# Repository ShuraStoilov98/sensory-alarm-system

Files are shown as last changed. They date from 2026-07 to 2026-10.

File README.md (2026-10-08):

# Sensory Alarm System

An ESP32 alarm that opens bedroom curtains with a stepper motor and a printed mechanism. A physical direction switch and hold-to-run button provide manual control; end stops and a five-second timeout bound each movement.

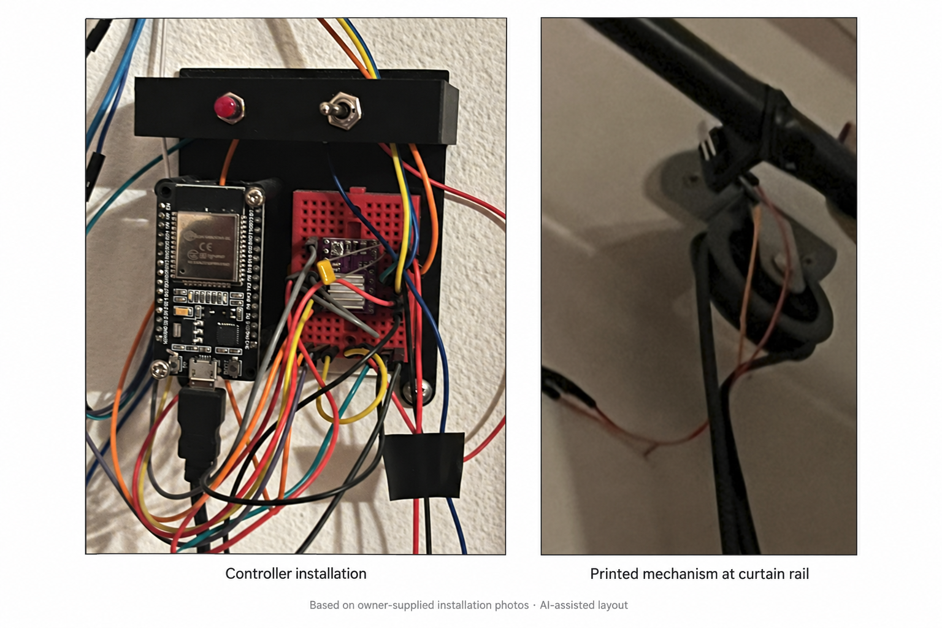
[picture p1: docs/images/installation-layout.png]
Photo-based layout of the original controller installation and printed curtain mechanism


*Based on the owner's installation screenshots; [AI-assisted layout](docs/images/installation-layout.txt). The controller close-up leads, with the curtain mechanism alongside it.*

[Wiring](docs/Electrical.md) · [Printable parts](docs/Mechanical.md) · [Hardware checks](docs/Validation.md) · [Public readiness](docs/public_readiness_report.md)

## The build

Simona Todorova and Alexander Stoilov built the original version over Christmas weekend in December 2024, using an Arduino Mega2560 for motor control, an ESP32 for WiFi/time, SolidWorks CAD, and a physical curtain installation.

Alexander's subsequent work migrated the firmware to PlatformIO and simplified the electronics to a single ESP32. The October 2026 public-readiness pass added hold-to-run control, cooperative motor stepping, latched faults, reliable offline manual control, daylight-saving rules, and date-based alarm tracking. Contributor names and original commit dates remain; personal email and CAD source-path metadata have been removed from the published historical revisions.

**Status:** personal hardware prototype. The earlier build was reported working; the revised firmware has automated behavior checks and a compile check, but still needs validation on the assembled hardware. The supplied installation photographs document the earlier assembly. An operating video is outside this release scope; the CAD animation below illustrates the original printable designs.

## Wiring

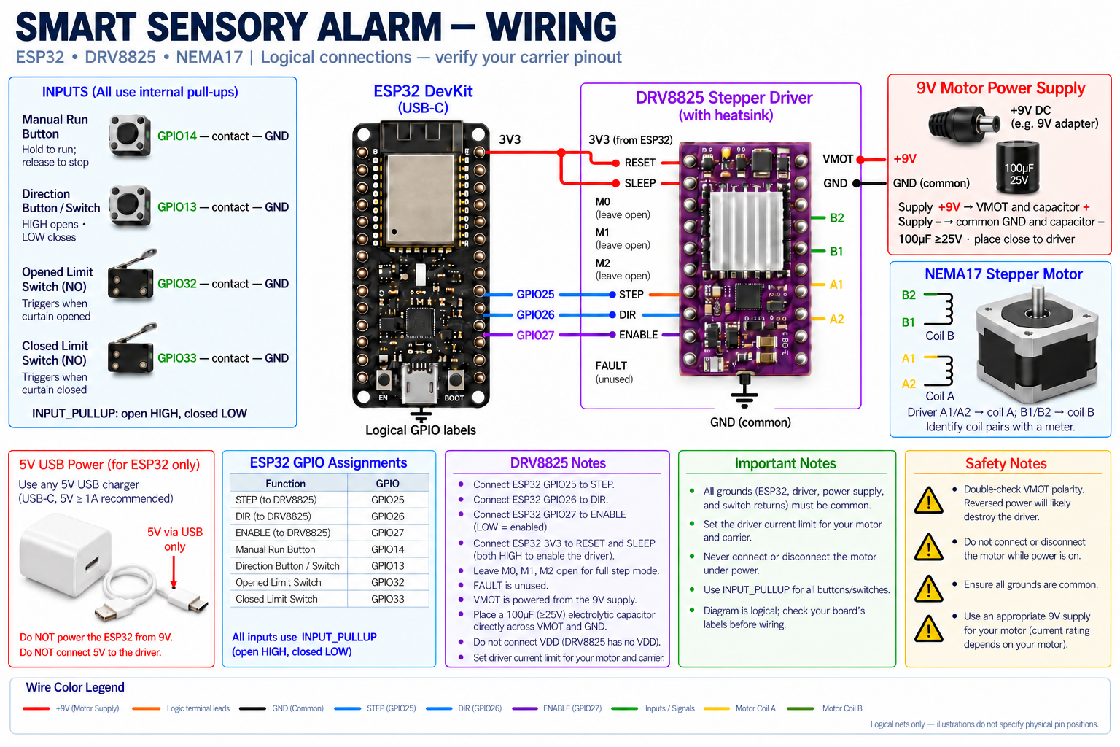
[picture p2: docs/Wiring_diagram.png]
ESP32 curtain alarm wiring: switches, DRV8825, motor and separate power supplies


*Regenerated logical wiring illustration. Follow the [connection tables](docs/Electrical.md) and check your actual board labels before assembly.*

## Printed mechanism

These are previews embedded in the original CAD exports, rather than photographs of the installed build. Download the models and read the [printing and assembly notes](docs/Mechanical.md).

| Curtain puller | Controller and driver holder | Button holder |
| --- | --- | --- |
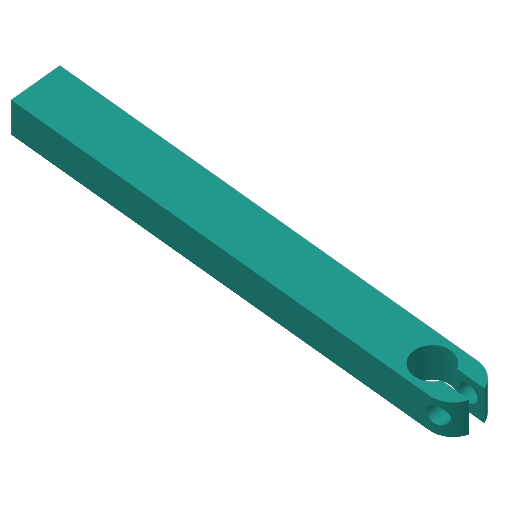
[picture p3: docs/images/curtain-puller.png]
Curtain puller CAD preview
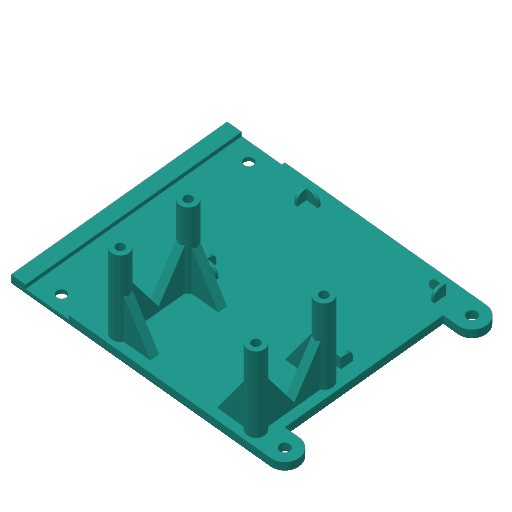
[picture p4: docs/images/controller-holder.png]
ESP32 and driver holder CAD preview
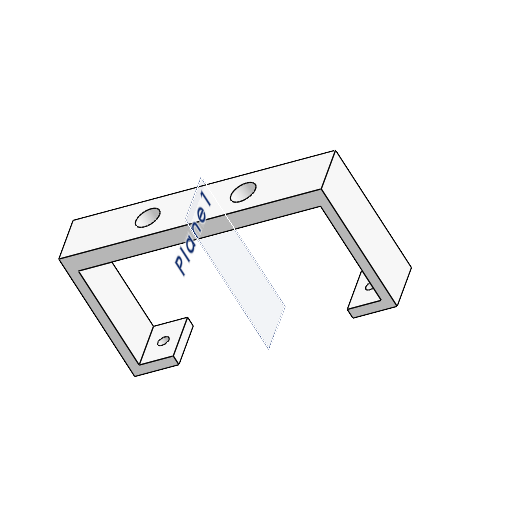
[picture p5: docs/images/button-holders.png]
Button holder CAD preview
|  |  |  |
| [CurtainPuller_v2.3mf](mechanical%20parts/CurtainPuller_v2.3mf) | [ESP32-DRV-BTNs_Holder.3mf](mechanical%20parts/ESP32-DRV-BTNs_Holder.3mf) | [Button_holders.3MF](mechanical%20parts/Button_holders.3MF) |

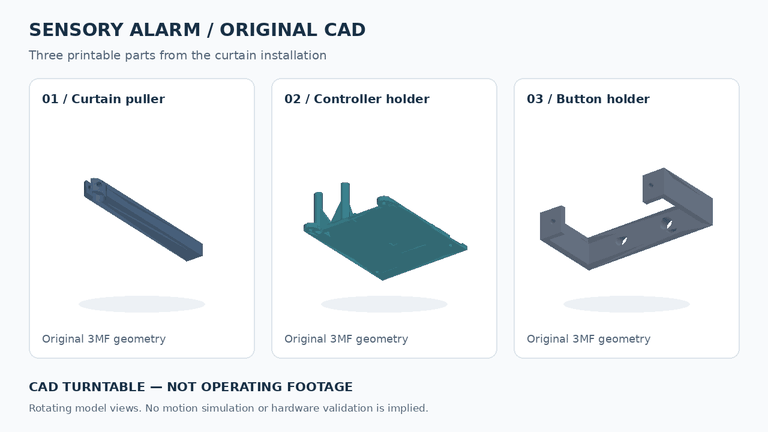
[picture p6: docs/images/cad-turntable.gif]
Rotating views of the three original CAD models, explicitly labeled as a CAD render


[Download the six-second CAD video](docs/images/cad-turntable.mp4). These are rotating views of the actual 3MF geometry, not footage of curtain operation. [Regenerate the render](tools/render_cad.py).

## How it works

```mermaid
flowchart LR
    TIME["WiFi and NTP"] --> ESP["ESP32"]
    BUTTON["Hold-to-run button and direction switch"] --> ESP
    LIMITS["Open and closed end stops"] --> ESP
    ESP -->|STEP DIR ENABLE| DRIVER["DRV8825"]
    DRIVER --> MOTOR["NEMA17"]
    MOTOR --> CURTAIN["Printed curtain mechanism"]
```

- **Manual:** select direction, then hold the run button. Release stops immediately on the next loop. Changing direction stops the current run; release and press again to move in the new direction. Manual control works without WiFi or valid time.
- **Automatic:** open at **06:30 Bulgarian local time**, with winter/summer timezone rules. The alarm can be evaluated throughout that minute; there is no late catch-up. A button press interrupts automatic movement, and manual activity during the scheduled minute suppresses that day's automatic run.
- **Daily tracking:** the automatic attempt date is saved in ESP32 NVS before movement, preventing a repeat after restart. An already-open curtain or manual/fault override consumes the day too; skipped dates encountered during travel are saved after movement stops. A power loss before that deferred save can lose the skipped-date record.
- **Motor:** STEP pulses are generated cooperatively, with 500µs minimum high/low intervals. No catch-up pulse bursts are emitted. WiFi reconnect requests and flash writes are deferred during travel.
- **Faults:** a five-second timeout or both limit switches active disables the driver and latches a fault until restart. Inspect the wiring and mechanism before restarting. A button held during boot must first be released.

The alarm time, GPIO assignments, timezone rules, and motor settings live in [config.h](src/esp32/config.h). Persisted attempt dates are independent of the compiled alarm setting; reflashing or rebooting is not a routine way to re-run today's alarm.

## Firmware structure

| File | Responsibility |
| --- | --- |
| [main.cpp](src/esp32/main.cpp) | Startup and cooperative loop |
| [config.h](src/esp32/config.h) | Pins, schedule, timezone and timing |
| [curtain_controller.cpp](src/esp32/curtain_controller.cpp) | State-aware command guards, limit checks, faults and step edges |
| [manual_input.cpp](src/esp32/manual_input.cpp) | Debounced hold-to-run input and physical override |
| [alarm_scheduler.cpp](src/esp32/alarm_scheduler.cpp) | Daily schedule and persistent attempt tracking |
| [network_clock.cpp](src/esp32/network_clock.cpp) | Idle WiFi recovery and SNTP startup |

The controller reports motion, limit-derived position, command source and fault cause separately. With neither end stop active, position is **unknown**. Busy requests cannot reverse an active movement; stop preserves latched faults. Manual input and the alarm share the same guarded command API. See the [state transitions](docs/improvements_brief.md#controller-state).

## Build and flash

Requires an ESP32 DevKit compatible with PlatformIO's `esp32dev` definition, a data-capable USB cable, and [PlatformIO Core or its VS Code extension](https://docs.platformio.org/en/latest/core/installation/index.html). The platform and Arduino framework revision are pinned in [platformio.ini](platformio.ini).

Copy the credential template, then edit only the local copy:

```bash
cp include/secrets.example.h include/secrets.h
```

`include/secrets.h` is ignored by Git. Keep personal credentials out of commits, screenshots, and downloadable firmware; compiled firmware contains the supplied credentials.

Compile, identify the serial port, then flash and monitor:

```bash
pio run --environment esp32
pio device list
pio run --environment esp32 --target upload
pio device monitor
```

The serial monitor uses **115200 baud**. If upload cannot connect, hold the board's BOOT button while connecting. Initially disconnect the motor PSU and verify logic before introducing motor movement. Follow the [wiring reference](docs/Electrical.md) and [commissioning checklist](docs/Validation.md) before running the assembled mechanism.

## Verification

Run the firmware behavior tests with Python 3 and a C++17 compiler on Linux, macOS or WSL:

```bash
python3 test/run_host_tests.py
```

The tests execute the actual firmware with fake GPIO, WiFi, flash storage, and clocks. They cover offline control, release-to-stop, debounce, alarm/manual interaction, timeout faults, end stops, persistent dates, timer rollover, and seasonal timezone behavior. They do not establish motor timing or electrical safety on the real board. [GitHub Actions](.github/workflows/checks.yml) runs the behavior tests and compiles with placeholder credentials; no firmware artifacts are uploaded.

Record physical results in [Validation.md](docs/Validation.md), including the actual carrier/motor model, current limit, curtain travel time, and end-stop behavior.

## Limitations and future work

End stops are polled by firmware and are not an independent hardware emergency stop. An unplugged switch reads inactive with the current pull-up wiring; there is no obstruction sensing. Driver disable at boot depends on software until the ESP32 configures the GPIO. Mechanical loads and restart behavior need physical validation.

Software-generated step timing can vary with ESP32 background work. Acceleration, editable/persistent alarm settings, a web interface, and OTA updates are not implemented. The [improvements brief](docs/improvements_brief.md) describes future extensions. The firmware is split into focused modules, with [main.cpp](src/esp32/main.cpp) coordinating input, movement, network recovery and scheduling.

The compile-tested PlatformIO baseline uses Arduino 2.0.17 / ESP-IDF 4.4.7. ESP-IDF 4.4 is [past vendor support](https://github.com/espressif/esp-idf/releases/tag/v4.4.8); a supported SDK migration remains necessary before treating this legacy prototype as maintained network-connected firmware.

## License

[MIT](LICENSE). See the build background above for original contributor credit.

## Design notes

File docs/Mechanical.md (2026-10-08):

# Printed parts and assembly

The repository contains three original 3MF exports from the curtain build. The previews below were extracted from those files; they show the designs rather than an installed or tested assembly.

| Part | Preview | Download |
| --- | --- | --- |
| Curtain puller | Curtain puller model | [CurtainPuller_v2.3mf](../mechanical%20parts/CurtainPuller_v2.3mf) |
| ESP32, driver and button holder | Controller holder model | [ESP32-DRV-BTNs_Holder.3mf](../mechanical%20parts/ESP32-DRV-BTNs_Holder.3mf) |
| Button holder | Button holder model | [Button_holders.3MF](../mechanical%20parts/Button_holders.3MF) |

## Installation and render

The [installation layout](images/installation-layout.png) uses the owner's controller close-up and curtain-mechanism screenshot as references, with AI-assisted formatting disclosed. It documents the earlier build's appearance rather than the revised firmware's operation.

Rotating original CAD models

[Download the CAD turntable video](images/cad-turntable.mp4). This six-second render uses the repository's three original 3MF meshes and assembly transforms. It shows rotating model views rather than a working mechanism or a motion simulation. An operating video is outside the current portfolio scope.

To regenerate the animation, install `numpy==2.3.3`, `Pillow==11.3.0` and `imageio-ffmpeg==0.6.0` in an optional tooling environment, then run `python3 tools/render_cad.py`. These packages are not firmware dependencies.

## Preparing a print

Open a 3MF in your slicer and inspect dimensions, orientation, supports and mounting holes. Two files contain a Bambu Studio export with a Flashforge Adventurer 5M 0.4mm-nozzle profile; choose settings for your own printer instead of treating those saved settings as validated print instructions. The exports contain model geometry and settings, not a prescribed ready-to-run print job.

The public-readiness pass removed Windows source-file paths from the two slicer archives. Their geometry and all other archive entries were preserved. The same metadata removal was applied to local historical copies; geometry and contributor attribution remain.

## Assembly details to record

The original installation was fitted to bedroom curtains. Reproducing that installation requires these physical details, which have not yet been recorded:

- Curtain/rail type, travel distance and load.
- Shaft coupling, fasteners, mounting dimensions and attachment method.
- Filament, orientation, layer height, walls/infill and required supports.
- Placement and actuation of both limit switches.
- Driver ventilation, cable strain relief and access to disconnect motor power.

Verify fit and mechanical clearance before powering the motor. Begin unloaded, check direction, and position both end stops before attaching the curtain load. Complete the [hardware checks](Validation.md) before describing the revised firmware as hardware-validated. Do not infer load-bearing strength from a CAD preview alone.

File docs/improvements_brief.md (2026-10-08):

# Improvements brief

Updated 8 October 2026. This brief distinguishes implemented behavior from proposed extensions. See the [entry point](../src/esp32/main.cpp) and [configuration](../src/esp32/config.h), the [wiring reference](Electrical.md), [printable parts](Mechanical.md), and [hardware validation](Validation.md).

## Implemented

The project migrated from Arduino IDE/local folders to PlatformIO and from an Arduino Mega plus ESP32 to an ESP32 alone.

The public-readiness pass adds:

- Focused modules for control, physical input, alarm persistence and network/time recovery.
- Cooperative `micros()`-based stepping with IDLE, OPENING, CLOSING and FAULT states.
- A shared guarded command API and separate motion, limit-derived position, control-source and fault status.
- Hold-to-run manual input with debounced starts and release-to-stop.
- Manual interruption of automatic movement and direction-change stop behavior.
- Latched timeout and contradictory-limit faults.
- Manual operation without WiFi/time, with reconnect requests deferred during travel.
- Bulgarian daylight-saving rules and an alarm evaluated throughout its scheduled minute.
- A persistent daily automatic-attempt date, saved before automatic movement.
- Host regression tests and a CI compile check using placeholder credentials.

Physical acceptance of the revised firmware remains pending. The limit-switch reliability issue mentioned in the earlier roadmap needs confirmation on the real mechanism; source changes and compile checks cannot establish closure.

## Current runtime

```mermaid
flowchart TD
    LOOP["loop()"] --> BUTTON["Debounce start / detect manual override"]
    BUTTON --> MOTOR["Check limits, release, direction and timeout; emit step edge if due"]
    MOTOR --> NETWORK["Request WiFi recovery / start SNTP when idle"]
    NETWORK --> ALARM["Check local date and schedule; persist attempt before auto start"]
    ALARM --> YIELD["Yield when idle"]
    YIELD --> LOOP
```

No WiFi connection wait or whole-travel motor loop blocks the application. Background SDK work and short flash operations still take time. Network reconfiguration and flash writes are deferred during movement; software pulse timing remains subject to hardware validation.

## Controller state

[Controller API](../src/esp32/curtain_controller.h) exposes `request(direction, source)`, `stop(reason)` and a read-only `status()` snapshot. Internal state and pulse timers are private. Requests return a result: started, busy, fault latched, already at target, manual override, or invalid source. Rejected requests preserve the current movement; contradictory limits latch a fault immediately.

```mermaid
stateDiagram-v2
    [*] --> IDLE
    IDLE --> OPENING: accepted open request
    IDLE --> CLOSING: accepted close request
    OPENING --> IDLE: open limit / stop / manual release or direction change
    CLOSING --> IDLE: closed limit / stop / manual release or direction change
    OPENING --> FAULT: timeout / contradictory limits
    CLOSING --> FAULT: timeout / contradictory limits
    IDLE --> FAULT: contradictory limits
    FAULT --> FAULT: all commands blocked; stop preserves fault
```

Fault recovery requires inspection and device restart; there is no software fault-clear command. A raw button press stops alarm-driven travel. A released button and new debounced press are required to start manual travel after that interruption.

Position is `OPEN` or `CLOSED` only while the corresponding end stop is active, `UNKNOWN` when neither is active, and `CONFLICT` when both are active. There is no encoder, homing sequence or remembered position estimate. Source is `MANUAL` or `ALARM` during travel and `NONE` after stopping. A consumed alarm date records an attempt, never a confirmed position.

All firmware modules remain under `src/esp32/`, covered by the existing PlatformIO source filter. Host tests compile those translation units separately and exercise the actual command API.

## Proposed extensions

| Extension | Status and prerequisite |
| --- | --- |
| Acceleration and hardware-timed stepping | Not implemented. Measure travel and step timing before changing the drive profile. |
| Supported SDK migration | Not implemented. The compile-tested PlatformIO Arduino 2.x environment uses an end-of-life ESP-IDF 4.4.7 baseline; validate a supported stack before maintained network deployment. |
| Editable alarm settings in NVS | Not implemented. Only the last handled alarm date is persisted; the hour/minute remain compiled settings. |
| Local web interface | Not implemented. Route authenticated open/close/stop commands through the same motor/fault logic. |
| OTA firmware updates | Not implemented. Require authenticated updates and a tested recovery strategy. |
| Light sensor, speaker, multiple curtains or voice integration | Ideas only; each needs its own hardware and behavior validation. |

## Web control design boundary

A possible future interface would offer status and authenticated commands on the local network, with a small device-served page. There is no current HTTP server or OTA endpoint.

Authentication and request validation must be part of the first implementation of actuator/configuration writes, rather than a later hardening phase. A local network alone does not establish caller identity. Define how browser requests are protected against unwanted cross-origin commands, how credentials are provisioned, and how a physical override takes priority. Do not expose the device through port forwarding as a shortcut.

Only persist settings when they change. Keep alarm-attempt tracking independent from editable configuration and avoid flash writes in the movement path.

## Next useful evidence

The supplied controller and mechanism screenshots are now surfaced in the README, with AI-assisted formatting disclosed. A CAD turntable video/GIF uses the original 3MF geometry. Filming an operating demo is outside this release scope.

Complete the [commissioning checks](Validation.md) and record the carrier and motor specifications before claiming the revised firmware is hardware-validated. Those checks can remain pending for a clearly documented prototype source release. See the [publication status and remaining checks](Publication.md).

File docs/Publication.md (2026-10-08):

# Publication decisions and remaining actions

The intended release is a documented personal hardware prototype. Filming a working demo is outside scope. The revised firmware has 22 passing behavior scenarios and an ESP32 compile check; physical acceptance is still pending and is disclosed in the README.

## Decisions made

| Item | Decision |
| --- | --- |
| Historical privacy | Remove personal author/committer emails and historical CAD source-file paths. Preserve contributor names, original dates, commit messages, source files and geometry. |
| Lead installation image | Use the bright controller close-up, screenshot 1. It clearly shows the ESP32, driver, controls and printed mounting. |
| Supporting image | Use screenshot 2 for the curtain mechanism. Its low-light appearance is retained; it provides installation context rather than fine mechanical detail. |
| Alternate images | Omit screenshots 3 and 4; they repeat the controller view with poorer exposure. |
| Image processing | The chat screenshots were not available as local files. The stored contact sheet is generated from those references and labeled as an AI-assisted layout. It is not an untouched screenshot export. |
| Video | Provide a six-second [CAD turntable](images/cad-turntable.mp4), with an [inline GIF](images/cad-turntable.gif). It renders the original 3MF geometry and is explicitly labeled as CAD, not operating footage. |
| Release scope | Publish the current stack as a documented legacy prototype. A supported SDK migration and bench acceptance are future maintenance work, not prerequisites for sharing prototype source honestly. |

## Published repository and future pushes

The cleaned history was published on 8 October 2026 to the independent [sensory-alarm-system repository](https://github.com/ShuraStoilov98/sensory-alarm-system). The initial upload contains 20 commits through `844dc80`, including the final presentation assets. The owner created this destination as public. The original repository's `main` was also updated successfully with an explicit force-with-lease.

The cleanup covered the preceding 19 commits: 30 personal author/committer email fields and two historical CAD path entries were removed. All other CAD archive entries remain byte-identical. Contributor names, dates and messages are preserved; rewritten commit IDs change and existing commit signatures cannot be retained as valid signatures. A follow-up check of all 20 commits on the published branch found no personal email fields or private Windows paths in CAD archives; the checkout secret scan found no credential candidates.

The local `public` remote points to `https://github.com/ShuraStoilov98/sensory-alarm-system.git`, and `main` tracks `public/main`. Future normal updates use:

```bash
git push
```

Push only reviewed branches. Do not publish the entire local ref namespace with `--mirror`, which could include tool-owned checkpoints or old history. The `.git/privacy-cleanup-lease` file records the completed original-repository update; it is local bookkeeping and is no longer the publication procedure.

Keep the original repository private. Re-clone other local copies from the new repository rather than merging previous history into the cleaned branch. An earlier pull fetched the old history locally but stopped before merging; the published `main` remains clean. A new repository isolates this release from the original repository's PR references and cached views, but does not erase old clones, forks or previously exposed copies. See [GitHub's history-cleanup guidance](https://docs.github.com/en/authentication/keeping-your-account-and-data-secure/removing-sensitive-data-from-a-repository).

Confirm [GitHub Actions](https://github.com/ShuraStoilov98/sensory-alarm-system/actions) passes on the published branch. The push succeeded; hosted CI and the rendered public README have not been independently verified in this pass. Keep a GitHub noreply address configured for future commits; use the exact address in your [GitHub email settings](https://docs.github.com/en/account-and-profile/how-tos/email-preferences/setting-your-commit-email-address) if profile attribution requires its numeric ID format.

## Final portfolio setup

1. Check the rendered README, images and diagrams in the public repository, and confirm GitHub Actions passes.
2. Use a concise description, for example: **ESP32 curtain-opening alarm with printed mechanics, offline manual control and fault-aware firmware.**
3. Add relevant topics such as `esp32`, `platformio`, `stepper-motor`, `3d-printing`, `embedded` and `alarm-clock`, then pin the repository if desired.
4. Keep the original collaborator credit and MIT license. The supplied pictures are authorized by the owner's request to use them; no additional filming is required.
5. Describe it as a personal prototype with an earlier installed build and a compile-tested firmware revision. The photo-based layout and CAD animation do not establish that the latest revision has been tested on hardware.

## Future maintenance

The pinned Arduino 2.0.17 / ESP-IDF 4.4.7 baseline is past vendor support; see the [vendor release notes](https://github.com/espressif/esp-idf/releases/tag/v4.4.8). Migrate before describing the device as maintained network-connected firmware. Keep web control, OTA and other optional features outside this release scope.

Complete [hardware acceptance](Validation.md) before making claims about the revised firmware's real pulse timing, current limit, end-stop reliability or loaded travel. Recording those results does not require making a video.

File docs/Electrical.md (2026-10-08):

# Electrical wiring reference

Logical connections for the ESP32 curtain prototype. The restored illustration retains the original visual style and corrects the earlier wiring errors. It was regenerated with AI and checked against the connection tables and manufacturer references below; it has not been validated on the physical assembly. Verify the exact ESP32 board and DRV8825 carrier against their manufacturer diagrams before assembly: the original carrier revision has not yet been recorded.

ESP32 curtain alarm wiring illustration

The illustration shows logical nets. The component artwork does not specify physical GPIO or carrier pin positions. Repeated GND symbols name one common ground; matching motor tags and input/power equations define the remaining connections. Use the labels printed on the actual board and its schematic. The tables below are the authoritative project mapping; an [editable overview](images/connections.svg) and [image generation notes](images/wiring-generation.txt) are also available.

## Components and power

| Component | Current design | Detail still needed |
| --- | --- | --- |
| Controller | ESP32 DevKit, `esp32dev` build target | Exact board/module and revision |
| Motor driver | DRV8825 carrier | Manufacturer, revision and sense-resistor values |
| Motor | Bipolar NEMA17 stepper | Part number, rated coil current and verified coil pairs |
| Controller supply | 5V through USB | USB supply/data cable suited to the board |
| Motor supply | Separate 9V DC supply; previous design recommended at least 2A | Actual supply rating and voltage under load |
| Local decoupling | 100µF electrolytic, at least 25V, near VMOT/GND | Installation and polarity confirmed on hardware |

The DRV8825 operating supply range is 8.2–45V. The proposed 9V supply is near the lower boundary, so verify that its voltage remains suitable under load. Use a supply sized for the actual motor and configured current limit, rather than treating NEMA17's frame size as an electrical specification. See the [TI datasheet](https://www.ti.com/lit/ds/symlink/drv8825.pdf) and [Pololu carrier reference](https://www.pololu.com/product/2133/).

Power the ESP32 through USB. Connect motor PSU positive to **VMOT** and negative to **driver GND**. Connect **ESP32 GND, driver GND, motor PSU negative and all switch grounds together**. Neither USB 5V nor ESP32 3V3 powers VMOT.

Place the bulk capacitor directly across VMOT and GND near the carrier, with its positive lead to VMOT. Pololu documents destructive LC supply spikes and recommends at least 47µF local bulk capacitance for its carrier; the original design specifies 100µF. A small onboard ceramic capacitor alone does not replace that bulk capacitor.

## Controller signals

These assignments match [config.h](../src/esp32/config.h):

| ESP32 | DRV8825 | Function |
| --- | --- | --- |
| GPIO25 | STEP | Step pulses |
| GPIO26 | DIR | HIGH opens; LOW closes, subject to motor orientation |
| GPIO27 | ENABLE / nENBL | HIGH disables; LOW enables |
| 3V3 | RESET / nRESET and SLEEP / nSLEEP | Hold both high for normal operation |
| GND | GND | Shared signal reference |

**Standard DRV8825 carriers do not have a VDD logic-supply input.** The A4988 VDD pin position is FAULT on standard DRV8825 carriers. Do not use the old diagram's VDD instruction. Some carriers include protection that makes a logic supply on FAULT tolerable for A4988 compatibility, but that must not be assumed for an unidentified clone. FAULT is not currently read by this firmware. Verify the actual carrier's pinout and circuit in its documentation.

The DRV8825 accepts 3.3V control signals. M0, M1 and M2 are left unconnected in the original full-step configuration; verify the carrier's pull-downs and selected mode. RESET/SLEEP must be high during operation. The former blanket instruction never to connect them to GND was misleading: low intentionally disables/resets or sleeps the driver.

GPIO27 is driven HIGH during firmware startup and whenever movement ends. Before that configuration, software cannot guarantee the driver's state. If an independently disabled boot state is needed, verify an appropriate external pull-up or hardware interlock for the actual carrier.

## Switches

All four inputs use `INPUT_PULLUP`. Each contact connects its GPIO to common GND when active.

| Input | ESP32 GPIO | Inactive | Active |
| --- | --- | --- | --- |
| Hold-to-run button | 14 | HIGH, released | LOW, held |
| Direction switch | 13 | HIGH, opening selected | LOW, closing selected |
| Opened limit | 32 | HIGH | LOW, fully open |
| Closed limit | 33 | HIGH | LOW, fully closed |

For switches with COM/NO/NC contacts, verify that the selected pair closes at the intended actuation point. The current logic expects an inactive-open, active-closed contact. A broken or unplugged wire therefore looks inactive; this circuit does not detect that fault independently.

The destination limit stops travel. Travel away from an active opposite limit is allowed. Both limits active together latch a fault. A manual release or direction change stops manual travel; changing direction requires a released button and a new press. A press during automatic travel interrupts it, then requires release before manual movement can begin.

## Motor and current limit

Connect one verified coil pair to A1/A2 and the other to B1/B2. Wire colors and carrier orientation vary: establish pairs with a continuity/resistance check while all supplies are disconnected. Do not copy the earlier assumed color/order table without verifying the actual motor.

Set the current limit according to the motor's rated coil current, the carrier's sense resistors, and cooling. The TI relation is `I_limit = VREF / (5 × R_sense)`. On the referenced Pololu carrier with 0.100Ω resistors this becomes `I_limit = 2 × VREF`; other carriers may differ. Measure and record the actual setting. The old generic 0.5–0.8A recommendation is not sufficient without the motor and carrier specifications.

Start with an unloaded mechanism, verify direction and limit behavior, and then test the installed curtain. Check driver/motor temperature and mechanical binding during repeated operation.

## Power and commissioning

Disconnect both supplies before rewiring. Never reverse VMOT polarity or plug/unplug motor leads while the driver is powered.

For the first logic checks, power only the ESP32 over USB with motor power disconnected. Verify that idle/fault states disable the driver, switches register the expected states, and release stops the manual command. Then connect the correctly wired motor supply for an unloaded test, keeping the supply accessible for immediate disconnection.

After a timeout or contradictory-limit fault, disconnect motor power, inspect the cause, and restart only when corrected. These software protections are not an independent emergency stop. Follow and record the [hardware validation checklist](Validation.md).

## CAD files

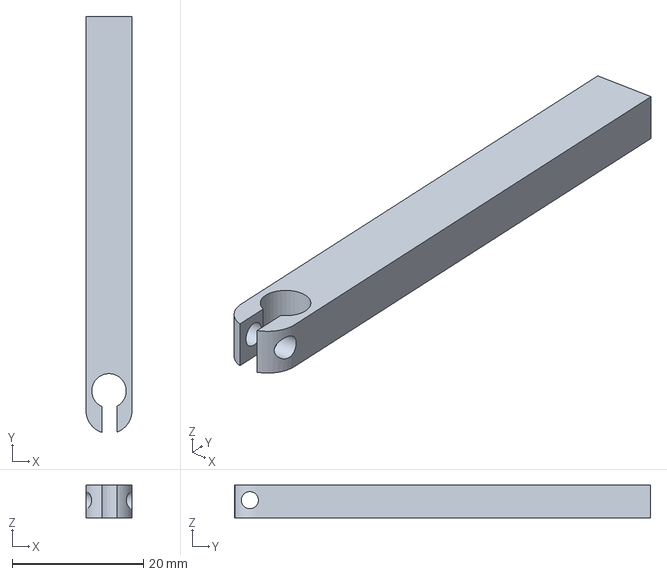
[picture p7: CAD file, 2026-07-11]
mechanical parts/CurtainPuller_v2.3mf
7.00 x 63.3 x 5.00 mm

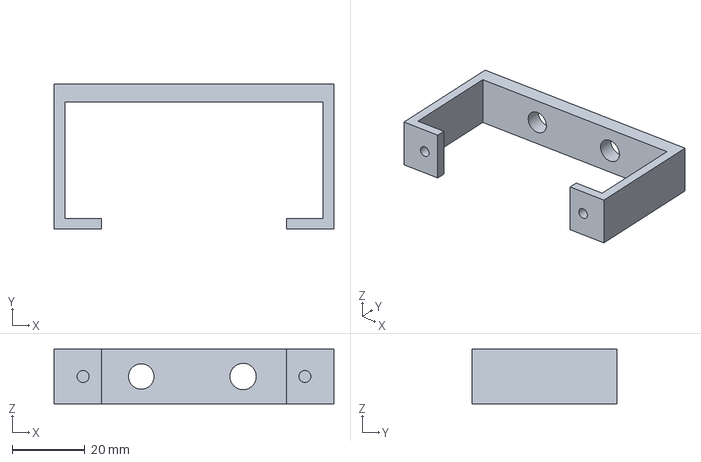
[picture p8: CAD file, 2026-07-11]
mechanical parts/Button_holders.3MF
77.0 x 40.0 x 15.0 mm

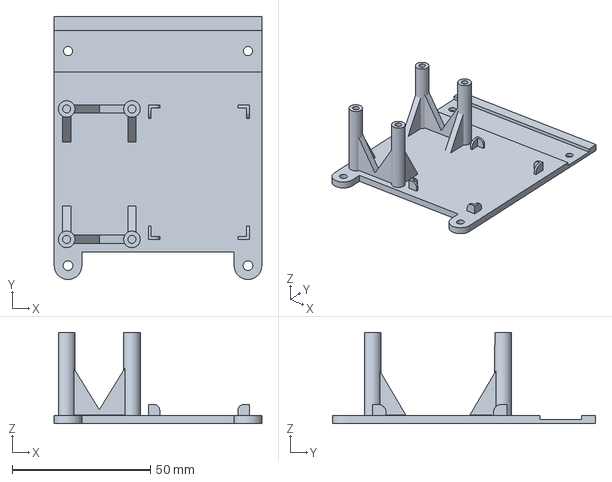
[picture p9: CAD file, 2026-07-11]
mechanical parts/ESP32-DRV-BTNs_Holder.3mf
75.0 x 95.0 x 33.0 mm

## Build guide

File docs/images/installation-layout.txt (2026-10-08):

Installation image selection and processing

Selected: supplied screenshot 1 (controller close-up) and screenshot 2 (curtain mechanism).
Omitted: screenshots 3 and 4; darker duplicate controller views.
The supplied attachments were visible in chat but were not available as local image files.
The repository asset is a generated, photo-based contact sheet, not an untouched export of the original screenshots.
Tool: built-in imagegen. The original hardware appearance was used as a strict visual reference.
This image is presentation material, not an authoritative wiring reference or evidence of the revised firmware running.
No real operating video is required for this portfolio release.

Final prompt:

Use case: compositing
Asset type: GitHub README contact sheet based on owner-supplied real installation screenshots.
Inputs: image 1 is the bright close-up of the real ESP32 controller mounted on a pale textured wall. Image 2 is the real dark vertical close-up of the printed curtain mechanism at its black rail. Images 3 and 4 are redundant alternate controller views and must NOT be used.
Make a tasteful plain-white two-photo layout using ONLY the first and second supplied photographs, controller first and larger on the left, original narrow mechanism photograph on the right. Preserve every pictured hardware component, wire, mounting part, red button, metal toggle switch, ESP32, purple driver and red breadboard exactly as in the source shots. Keep source photographs' original angle, framing, aspect ratio, background, lighting and exposure. Copy photo contents faithfully. No new camera view, new hardware, new wires, cosmetic rewiring, background replacement, cleaned-up installation, enhanced hidden detail or fake motion. Do not invent a better mechanism from the blurry photograph. Keep the uneven exposed prototype wiring: this is evidence of the original build.
Only add whitespace, a fine neutral border and crisp captions BELOW the photographs: "Controller installation" and "Printed mechanism at curtain rail".
Add a small footer exactly "Based on owner-supplied installation photos · AI-assisted layout".
No other text, branding or claims of hardware validation. The final must look like a modest contact sheet, not an idealized product render.

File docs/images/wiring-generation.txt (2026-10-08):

Wiring illustration regeneration

Tool: built-in imagegen.
Style reference: docs/Wiring_diagram.png at original commit cc3a14f.
Electrical reference: docs/Electrical.md and src/esp32/config.h.
The illustration defines logical nets. Component renders do not specify physical pin positions.
Intermediate generated drafts were visually checked and corrected before selecting the final image.
Hardware acceptance remains pending.

Initial generation specification:

Use case: infographic-diagram
Asset type: professional GitHub README wiring illustration for a real curtain alarm prototype.
Primary request: regenerate the reference's polished white-background electronics infographic, with realistic ESP32 DevKit, purple DRV8825 carrier/heatsink, four tactile/limit switches, NEMA17 motor, USB charger and 9V supply, thin colored orthogonal wires, excellent typography. Preserve its professional visual character, but rebuild the wiring correctly. Wide landscape high resolution, readable concise labels.
Input image 1 is STYLE reference only, containing electrical errors that MUST NOT be copied.
Title exactly "SMART SENSORY ALARM — WIRING"
Subtitle exactly "ESP32 · DRV8825 · NEMA17 | Logical connections — verify your carrier pinout"
Use component illustrations with clearly labeled functional terminal rails beside them. Wires attach to labeled functional terminals, not invented physical GPIO pads. Do not print a fake physical DevKit pinout. No unnecessary pins.
Exact electrical nets, every route visible:
ESP32 GPIO25 -> DRV8825 STEP (blue).
ESP32 GPIO26 -> DRV8825 DIR (blue).
ESP32 GPIO27 -> DRV8825 ENABLE (purple), labeled "LOW = enabled".
ESP32 3V3 -> both DRV8825 RESET and SLEEP (red/orange 3.3V net distinct from motor9V).
DRV8825 M0, M1, M2 unconnected, labeled "Full step: leave M0/M1/M2 open".
DRV8825 FAULT unconnected; label "FAULT unused". There is NO VDD input on DRV8825; never draw VDD.
Separate motor supply +9V red line -> VMOT. Supply negative -> common GND.
100µF capacitor rated ≥25V directly across VMOT and GND, clear "+" to VMOT and "-" to GND.
Common black GND bus connects ESP32 GND, DRV8825 GND, motor supply negative, and all four switch return contacts.
ESP32 receives 5V via USB cable only, charger plugs to ESP32 USB. No 9V-to-ESP32 or 5V-to-driver wiring.
Four two-terminal normally-open contacts: manual run button GPIO14 to GND; direction switch GPIO13 to GND; opened limit GPIO32 to GND; closed limit GPIO33 to GND. EACH switch's signal end connects its GPIO, opposite end connects GND, never short GPIO directly to ground beside switch. Label "INPUT_PULLUP: open HIGH, closed LOW". Label manual "Hold to run; release to stop". Direction "HIGH opens · LOW closes".
DRV8825 A1/A2 -> two ends of motor coil A; B1/B2 -> two ends of separate motor coil B. Show two independent coil symbols clearly and realistic motor nearby. Never imply motor wire colors identify coil pairs. Label "Identify coil pairs with a meter".
Bottom compact ESP32 GPIO table with exact seven GPIO assignments above. Bottom notes: "Set driver current limit for your motor and carrier." "Never connect or disconnect the motor under power." "Diagram is logical; check board labels before wiring."
Avoid overcrowding, crossing ambiguous wires, unsupported 2A recommendation, physical pin-order claims, any VDD pin, fake provenance or 'verified hardware' claims. Ensure the 9V positive visibly reaches VMOT and RESET/SLEEP visibly reach 3V3.

Final editing prompt (applied to the corrected intermediate illustration):

Fix ONLY the top-right power supply panel and its two connections to the driver. Preserve the entire rest of this infographic, its polished visual style, component illustrations, title, correct GPIO wiring, switches, motor coil nets, tables, notes and footer.
The present power-panel traces incorrectly cross and short capacitor positive to ground. REMOVE EVERY electrical wire and junction dot INSIDE the 9V Motor Power Supply panel. Keep the barrel-adapter and capacitor illustrations as decorative component photos only, with no wires attached to them. Define power connections with this exact three-line net table inside the panel:
"Supply +9V → VMOT and capacitor +"
"Supply − → common GND and capacitor −"
"100µF ≥25V · place close to driver"
Use readable black type, with plus red and minus black. No diagram wires inside this panel, no intersections, no junctions. Adjust illustration sizes to fit the table cleanly.
Outside this panel, DRV8825 VMOT gets ONLY a short red terminal stub with the net tag "+9V". DRV8825 GND gets ONLY a short black terminal stub with net tag "GND (common)". Neither stub extends into the power panel. Matching named nets specify the connections, as already done for the motor outputs and input switches.
Keep driver RESET/SLEEP tied to ESP32 3V3, all control GPIO lines, driver ground symbol, ESP32 common ground symbol, motor coils, and correct notes unchanged.
In the bottom wire legend change the orange entry text from "3.3V (ESP32)" to "Logic terminal leads" so the color legend matches the pictured orange terminal segments. No new traces anywhere. Return the complete professional infographic.

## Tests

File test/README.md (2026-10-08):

# Firmware behavior tests

Run `python3 test/run_host_tests.py` from the repository root with Python 3 and a C++17 compiler on Linux, macOS or WSL. Set `CXX` if the compiler is not available as `c++`, for example `CXX=g++ python3 test/run_host_tests.py`.

The host harness compiles every production `src/esp32/*.cpp` separately with fake Arduino GPIO, WiFi and Preferences implementations. A forced test header redirects wall-clock reads to the simulated clock. Each scenario runs in its own process. Time conversion uses the host C library; GPIO step edges and elapsed time are simulated.

The checks exercise offline manual control, reconnect, boot with a held button, debounce and raw release, manual control after the alarm, full-minute scheduling, date persistence and rollback, latched faults, limit/direction behavior, manual override, failed storage, timer rollover and Bulgarian seasonal time. Additional command tests cover source ownership, limit-derived position, busy request rejection, manual guards, and stop preserving a latched fault. All 22 scenarios pass.

They do not verify physical pin mapping, current limits, ESP32 background scheduling, electrical faults, motor acceleration, actual pulse timing or curtain mechanics. Record those separately in [Validation.md](../docs/Validation.md).

Temporary executables are created outside the repository and removed after each run. Test credentials are placeholders in `host/stubs/secrets.h`; the harness never reads local WiFi credentials.

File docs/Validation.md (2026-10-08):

# Hardware validation and publication checklist

The revised firmware has host behavior tests and a successful ESP32 compile check. Physical checks below remain **pending**. Fill in observed results from the actual assembly before describing the revision as hardware-validated.

## Recorded build check

Validated on 8 October 2026 with placeholder WiFi credentials:

| Item | Version or result |
| --- | --- |
| PlatformIO Core | 6.1.18 |
| Espressif32 platform | 7.1.3 |
| Arduino framework package | 4.20017.260907+sha.dcc1105b, explicitly pinned |
| Arduino core / underlying ESP-IDF | 2.0.17 / 4.4.7, from installed version headers |
| ESP32 toolchain | 8.4.0+2021r2-patch5 |
| Upload tool | esptool 4.11.0, package 2.41100.260830 |
| Target | `esp32dev`, release build |
| Firmware behavior tests | 22 host scenarios passed |
| RAM | 45,084 / 327,680 bytes, 13.8% |
| Flash | 751,825 / 1,310,720 bytes, 57.4% |
| Device upload or bench run | Not performed |
| Hosted GitHub Actions run | Pushed to the new public repository; hosted result not independently verified, commands verified locally |

The platform and framework pins make the selected platform/SDK explicit. They do not certify the security of every SDK component or freeze all Python/upload-tool dependencies. The underlying ESP-IDF 4.4 branch reached end of life in July 2024, according to the [vendor's final 4.4 release notes](https://github.com/espressif/esp-idf/releases/tag/v4.4.8). This pass preserves the PlatformIO Arduino 2.x baseline; migration to a supported SDK remains a separate build/bench task before treating the device as maintained network-connected firmware.

## Assembly record

| Detail | Observed value |
| --- | --- |
| ESP32 board/module and revision | Pending |
| Driver carrier manufacturer/revision | Pending |
| Carrier sense resistors and measured VREF | Pending |
| Motor part number and rated coil current | Pending |
| Verified coil pairs | Pending |
| PSU rating and measured loaded voltage | Pending |
| Bulk capacitor value/rating/polarity/placement | Pending |
| Printed material and slicer settings | Pending |
| Mechanism, coupling, fasteners and travel distance | Pending |
| Loaded opening/closing duration | Pending |

## Bench checks

Begin with motor power disconnected and follow [Electrical.md](Electrical.md). Perform motor tests unloaded before connecting the curtain. Keep power disconnection accessible; do not intentionally jam the installed mechanism to test a fault.

| Check | Expected behavior | Actual result |
| --- | --- | --- |
| Boot with button released | Driver disabled; no spontaneous movement | Pending |
| Boot with run button held | No movement until released and pressed again | Pending |
| Cold boot without WiFi/NTP | Manual holding still commands travel; releasing stops | Pending |
| Restore WiFi after offline boot | Reconnect requested while idle; NTP service starts after connection | Pending |
| Hold manual button in each direction | Correct physical direction; release stops promptly | Pending |
| Change direction while holding | Movement stops; no reversal until release and new press | Pending |
| Activate each destination limit | Stops promptly and disables driver; held button does not restart | Pending |
| Move away from the opposite active limit | Allowed in the correct direction | Pending |
| Simulate both limits active with motor power disconnected | Fault latched; no further movement commands until restart | Pending |
| Simulate absent destination limit on an unloaded bench motor | Stops at five seconds; held/repeated button presses cannot restart the latched fault | Pending |
| Automatic opening | Begins during scheduled minute when time is valid and no override/fault applies | Pending |
| Press button during automatic travel | Stops; held input does not restart; release then hold selects manual movement | Pending |
| Close manually after automatic opening | Manual closing works on the same day | Pending |
| Restart during the alarm minute after an automatic attempt | Persisted date prevents a second automatic attempt | Pending |
| Manual activity during scheduled minute | Suppresses automatic travel for that day; skipped date saved once idle | Pending |
| Pulse timing and loaded travel | No missed steps/binding; travel fits within timeout with margin | Pending |
| Repeated loaded runs and WiFi loss | Stable movement, reliable end stops, acceptable temperatures | Pending |

For alarm testing, changing the hour/minute in the source does not clear today's persisted attempt. Use a separate commissioning namespace or test device if repeated same-day alarm tests are required; restore the normal namespace and schedule afterwards. Do not routinely erase flash or reset the device to bypass fault inspection.

The daily record is a monotonic calendar date. A clock set incorrectly far into the future can suppress later alarms until that date is reached. Inspect/correct time and the saved record deliberately if this occurs. If a skipped date is awaiting an idle flash write when power fails, that skipped-date record can be lost. Automatic movement always requires a successful write first.

## Publication status and remaining human checks

| Decision or task | Current handling |
| --- | --- |
| Historical private metadata | Owner authorized removal. A verified history preserves 19 commits, names, dates, messages, source files and model geometry while removing 30 personal email fields and two historical CAD path entries. The cleaned branch and final presentation commit were published to the independent public repository; 20 commits on `main` have no personal email fields or private Windows paths in CAD archives. |
| Publish rewritten history | Completed: guarded update of the original repository and main-only upload to the independent public repository both succeeded. Old clones and the original repository may still retain historical data outside the published branch. See [publication status](Publication.md). |
| Contributor attribution and ownership | Confirm original collaborator credit is accurate and public attribution is welcome. Confirm the CAD/assets are yours or shared with permission to publish under the repository license. |
| Installation media | Supplied photo 1 leads and photo 2 supports the mechanism; the stored layout discloses AI-assisted processing. A six-second CAD video/GIF is provided. Filming an operating demo is outside scope and is not a publication requirement. |
| Exact hardware and fault behavior | Bench acceptance remains pending and is disclosed. Complete the assembly record and checks before claiming this revision is hardware-validated; confirm the five-second timeout suits the installed travel. Faults require inspection and restart; manual control is hold-to-run, as selected by the owner. |
| Legacy SDK | Decide whether to publish as a documented legacy prototype or migrate to an Arduino/ESP-IDF stack with current support. The existing compile-tested PlatformIO environment still uses ESP-IDF 4.4.7; pinning alone does not resolve SDK vulnerabilities. |
| GitHub publication | The owner created the new repository as public and uploaded only cleaned `main`. Confirm hosted CI and the rendered README; keep the original private and avoid copying old branches, artifacts or releases into the new repository. |
| Portfolio placement | Add a concise repository description/topics, pin the project if desired, and use the installation layout and CAD animation. Describe the device as a personal prototype until physical acceptance is recorded. |

See the [public-readiness report](public_readiness_report.md) for the original review and the status of its findings.

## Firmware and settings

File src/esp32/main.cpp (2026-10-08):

#include <Arduino.h>
#include "alarm_scheduler.h"
#include "curtain_controller.h"
#include "manual_input.h"
#include "network_clock.h"

CurtainController controller;
ManualInput manualInput;
NetworkClock networkClock;
AlarmScheduler alarmScheduler;

void setup() {
  Serial.begin(115200);
  controller.begin();
  manualInput.begin();
  alarmScheduler.begin();
  networkClock.begin();
  Serial.println("Ready: hold manual button to run; release to stop");
}

void loop() {
  manualInput.update(controller);
  controller.update();
  networkClock.update(controller.isMoving());
  alarmScheduler.update(controller, manualInput);
  // Software step timing still needs physical validation.
  if (!controller.isMoving()) {
    delay(1);
  }
}

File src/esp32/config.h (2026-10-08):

#pragma once

#include <cstdint>

namespace Config {
// Matches docs/Electrical.md. All switches are active LOW.
constexpr int STEP_PIN = 25;
constexpr int DIR_PIN = 26;
constexpr int ENABLE_PIN = 27;
constexpr int BUTTON_PIN = 14;
constexpr int DIR_BUTTON = 13;
constexpr int KILL_SWITCH_CLOSED_PIN = 33;
constexpr int KILL_SWITCH_OPENED_PIN = 32;

constexpr int ALARM_HOUR = 6;
constexpr int ALARM_MINUTE = 30;
// Bulgaria: UTC+2 in winter, UTC+3 in summer.
constexpr const char* TIMEZONE = "EET-2EEST,M3.5.0/3,M10.5.0/4";
constexpr const char* NTP_SERVER = "pool.ntp.org";
constexpr uint32_t STEP_HALF_PERIOD_US = 500;
constexpr uint32_t MOTOR_TIMEOUT_MS = 5000;
constexpr uint32_t BUTTON_DEBOUNCE_MS = 30;
constexpr uint32_t WIFI_RETRY_MS = 10000;
constexpr uint32_t TIME_CHECK_MS = 250;

} // namespace Config

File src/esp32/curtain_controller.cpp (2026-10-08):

#include "curtain_controller.h"
#include "config.h"
#include <Arduino.h>

using namespace Config;

void CurtainController::begin() {
  // Set output latches before configuring outputs to avoid an enable glitch.
  digitalWrite(ENABLE_PIN, HIGH);
  pinMode(ENABLE_PIN, OUTPUT);
  digitalWrite(STEP_PIN, LOW);
  pinMode(STEP_PIN, OUTPUT);
  pinMode(DIR_PIN, OUTPUT);
  pinMode(KILL_SWITCH_CLOSED_PIN, INPUT_PULLUP);
  pinMode(KILL_SWITCH_OPENED_PIN, INPUT_PULLUP);
}

CurtainStatus CurtainController::status() const {
  const bool opened = digitalRead(KILL_SWITCH_OPENED_PIN) == LOW;
  const bool closed = digitalRead(KILL_SWITCH_CLOSED_PIN) == LOW;
  const CurtainPosition position = opened && closed ? CurtainPosition::CONFLICT :
      opened ? CurtainPosition::OPEN : closed ? CurtainPosition::CLOSED :
      CurtainPosition::UNKNOWN;
  return {motion_, position, source_, fault_};
}

bool CurtainController::isMoving() const {
  return motion_ == MotorState::OPENING || motion_ == MotorState::CLOSING;
}

void CurtainController::disableDriver() {
  digitalWrite(ENABLE_PIN, HIGH);
  digitalWrite(STEP_PIN, LOW);
  stepHigh_ = false;
  source_ = ControlSource::NONE;
}

void CurtainController::stop(const char* reason) {
  disableDriver();
  // Stop never acknowledges or clears a latched fault.
  if (motion_ != MotorState::FAULT) {
    motion_ = MotorState::IDLE;
  }
  Serial.println(reason);
}

void CurtainController::latchFault(FaultReason reason, const char* message) {
  disableDriver();
  motion_ = MotorState::FAULT;
  fault_ = reason;
  Serial.println(message);
}

CommandResult CurtainController::request(Direction direction, ControlSource source) {
  if (motion_ == MotorState::FAULT) {
    return CommandResult::FAULT_LATCHED;
  }
  const CurtainPosition position = status().position;
  if (position == CurtainPosition::CONFLICT) {
    latchFault(FaultReason::CONTRADICTORY_LIMITS,
               "FAULT: both limits active; inspect wiring and restart");
    return CommandResult::FAULT_LATCHED;
  }
  if (isMoving()) {
    return CommandResult::BUSY;
  }
  if (source != ControlSource::MANUAL && source != ControlSource::ALARM) {
    return CommandResult::INVALID_SOURCE;
  }
  const bool opening = direction == Direction::OPEN;
  const bool held = digitalRead(BUTTON_PIN) == LOW;
  if ((source == ControlSource::ALARM && held) ||
      (source == ControlSource::MANUAL &&
       (!held || (digitalRead(DIR_BUTTON) == HIGH) != opening))) {
    return CommandResult::MANUAL_OVERRIDE;
  }
  if (position == (opening ? CurtainPosition::OPEN : CurtainPosition::CLOSED)) {
    return CommandResult::ALREADY_AT_TARGET;
  }

  digitalWrite(STEP_PIN, LOW);
  digitalWrite(DIR_PIN, opening ? HIGH : LOW);
  motion_ = opening ? MotorState::OPENING : MotorState::CLOSING;
  source_ = source;
  stepHigh_ = false;
  movementStartedMs_ = millis();
  lastStepUs_ = micros();
  digitalWrite(ENABLE_PIN, LOW);
  Serial.println(opening ? "Opening curtain" : "Closing curtain");
  return CommandResult::STARTED;
}

void CurtainController::update() {
  const CurtainPosition position = status().position;
  if (position == CurtainPosition::CONFLICT && motion_ != MotorState::FAULT) {
    latchFault(FaultReason::CONTRADICTORY_LIMITS,
               "FAULT: both limits active; inspect wiring and restart");
  }
  if (!isMoving()) {
    return;
  }
  const bool opening = motion_ == MotorState::OPENING;
  if (position == (opening ? CurtainPosition::OPEN : CurtainPosition::CLOSED)) {
    stop("Stopped: destination limit reached");
    return;
  }
  if (source_ == ControlSource::MANUAL && digitalRead(BUTTON_PIN) != LOW) {
    // Raw release stops immediately; debounce is needed only to start.
    stop("Stopped: manual button released");
    return;
  }
  if (source_ == ControlSource::MANUAL &&
      (digitalRead(DIR_BUTTON) == HIGH) != opening) {
    stop("Stopped: direction changed; release and press to run again");
    return;
  }
  if (static_cast<uint32_t>(millis() - movementStartedMs_) >= MOTOR_TIMEOUT_MS) {
    latchFault(FaultReason::TRAVEL_TIMEOUT,
               "FAULT: movement timed out; inspect mechanism and restart");
    return;
  }
  const uint32_t nowUs = micros();
  if (static_cast<uint32_t>(nowUs - lastStepUs_) >= STEP_HALF_PERIOD_US) {
    // Emit one edge, never a catch-up burst after a delayed loop.
    lastStepUs_ = nowUs;
    stepHigh_ = !stepHigh_;
    digitalWrite(STEP_PIN, stepHigh_ ? HIGH : LOW);
  }
}

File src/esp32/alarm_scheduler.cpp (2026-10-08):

#include "alarm_scheduler.h"
#include "config.h"
#include <Arduino.h>
#include <time.h>

using namespace Config;

void AlarmScheduler::begin() {
  storageReady_ = storage_.begin("curtain-alarm", false);
  if (storageReady_) {
    lastDate_ = storage_.getInt("last-date", 0);
  } else {
    Serial.println("Alarm storage unavailable; manual control remains enabled");
  }
}

void AlarmScheduler::update(CurtainController& controller, ManualInput& manualInput) {
  const uint32_t nowMs = millis();
  if (static_cast<uint32_t>(nowMs - lastCheckMs_) < TIME_CHECK_MS) {
    return;
  }
  lastCheckMs_ = nowMs;
  const bool manualOverride = manualInput.takeActivity();
  if (datePending_ && !controller.isMoving()) {
    datePending_ = false;
    if (!storageReady_ || storage_.putInt("last-date", lastDate_) != sizeof(lastDate_)) {
      Serial.println("Cannot persist skipped alarm date");
    }
  }
  time_t now;
  time(&now);
  struct tm localTime;
  // getLocalTime() can wait even with a zero timeout; read the clock directly.
  if (!localtime_r(&now, &localTime) || localTime.tm_year <= 2016 - 1900) {
    return;
  }
  const int32_t date = (localTime.tm_year + 1900) * 10000 +
                       (localTime.tm_mon + 1) * 100 + localTime.tm_mday;
  if (localTime.tm_hour != ALARM_HOUR || localTime.tm_min != ALARM_MINUTE ||
      date <= lastDate_) {
    return;
  }

  // Consume this date even on a manual override, fault or already-open curtain.
  lastDate_ = date;
  const CurtainStatus status = controller.status();
  if (manualOverride || status.motion != MotorState::IDLE ||
      digitalRead(BUTTON_PIN) == LOW || status.position == CurtainPosition::OPEN) {
    // Flash writes are deferred until travel ends to avoid disrupting pulses.
    datePending_ = true;
    Serial.println("Alarm skipped: manual control, limit or fault");
    return;
  }
  // Persist before automatic movement so a reboot cannot cause an auto retry.
  if (!storageReady_ || storage_.putInt("last-date", date) != sizeof(date)) {
    Serial.println("Alarm skipped: cannot persist daily attempt");
    return;
  }
  const CommandResult result = controller.request(Direction::OPEN, ControlSource::ALARM);
  if (result != CommandResult::STARTED) {
    Serial.println("Alarm request blocked by controller state");
  }
}

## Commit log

2026-04-15 Initialised repo with PlatfomIO and transfered across and debuged latest working version of codebase from local folders and Arduino IDE - moved wifi details in secrets.h and minor tweaks to code
2026-04-15 Refactored code in attempt to remove arduin mega2560 as reduntant and simplify and streamline system with only ESP32 - v0.1 untested
2026-04-15 Added a README.md file with description of current state - v1 to be updated as project progresses
2026-05-10 Updating code after wiring and testing ESP32, DRV, Nema connection and verifying code works with Serial as required 115600
2026-05-10 Adding wiring docs
2026-05-11 Include wiring process diagram note in Electrical documentation
    Added a note about using diagram for model enhancement.
2026-05-11 3mf. files of CAD models for 3D printing component
    [Button_holders.3MF]
2026-05-11 ESP32 DRV holder part 3mf file
    [ESP32-DRV-BTNs_Holder.3mf]
2026-10-08 feat: code refactor and push button behavior change
